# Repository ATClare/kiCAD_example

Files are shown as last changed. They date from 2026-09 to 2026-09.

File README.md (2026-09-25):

# ESP32 soil moisture and servo valve — Rev A

An engineer-reviewable, low-voltage irrigation prototype: a capacitive soil probe, ESP32 controller, servo-operated valve interface, three panel LEDs, printable enclosure, and a local web dashboard with moisture history and threshold notifications.

**Release status:** design prototype. Electronic connectivity, CAD geometry, firmware compilation, and software behavior can be checked without hardware. Valve torque, actual closure, water flow, electrical transients, moisture calibration, and printed-part fit require the acceptance tests below. This package is not a validated unattended watering product.

## Start here

| Deliverable | File |
|---|---|
| Electronic schematic, readable without KiCad | [Schematic PDF](electronics/soil_valve.pdf) |
| Editable schematic and project | [KiCad project](electronics/soil_valve.kicad_pro), [schematic](electronics/soil_valve.kicad_sch) |
| Component list and exact connectivity | [BOM](electronics/bom.csv), [net map](electronics/connectivity.json), [KiCad-exported netlist](electronics/soil_valve.net.xml) |
| Editable parametric CAD | [CadQuery model](mechanical/enclosure.py) |
| Assembled enclosure CAD | [STEP assembly](mechanical/exports/enclosure_assembly.step) |
| Individual STEP and print-ready STL files | [CAD exports](mechanical/exports/) |
| ESP32 application and control logic | [main.cpp](firmware/src/main.cpp), [control.h](firmware/include/control.h) |
| Dashboard | [Interactive offline demo](docs/dashboard-demo.html), [HTML source](firmware/web/index.html), [demo screenshot](docs/dashboard-demo.png) |
| Engineering rationale, wiring and procurement | [Electrical design](docs/electrical-design.md) |
| Mechanical dimensions and assembly | [Mechanical design](docs/mechanical-design.md) |
| Failure analysis and bench sign-off | [Audit and acceptance plan](docs/audit-and-acceptance.md) |
| Automated verification evidence | [Verification report](docs/verification.md) |
| Manufacturer references | [Sources](docs/sources.md) |

To preview the dashboard without a device, open `docs/dashboard-demo.html` in a browser. Alternatively, open `firmware/web/index.html` and append `?demo=1` to its address. The demo explicitly labels its simulated data and disables hardware controls. The dashboard needs no CDN, JavaScript framework, cloud service, or internet connection.

## Design assumptions

- One indoor/sheltered plant zone, externally supplied regulated **5.0 V / 3 A** power.
- Genuine **Espressif ESP32-DevKitC V4 with ESP32-WROOM-32E**, using the documented 38-pin headers. Other ESP32 boards need pin and power-path review.
- **DFRobot SEN0193** capacitive probe supplied at 3.3 V; only its sensing section enters soil. Do not immerse its electronics.
- **Hitec HS-311** positional servo, externally mounted above the water path. A small low-pressure valve must have measured torque and compatible linkage travel. The servo bracket and slotted linkage plate are supplied, but the valve-specific attachment dimensions are not known.
- A gravity reservoir is the intended first test source; use a spill tray and limit available water. No pressure-bearing printed plumbing parts are supplied.
- Measurement is **relative moisture percent**, not volumetric water content (VWC). Actual VWC requires soil-specific reference measurements and a different calibration model.

No valve, supply, or existing parts were specified. These assumptions make the design concrete; substitutions and the actual valve are audit inputs rather than proven equivalents.

## Operation

At power-on the firmware commands the servo to its configured closed position, leaves automatic watering disarmed, starts measurements, and creates a password-protected Wi-Fi access point. Calibration survives restart; arming, faults, watering reservations, graph history, and events do not. The boot event makes this reset visible.

The probe is sampled at 4 Hz, averaging 16 calibrated ADC millivolt readings per sample and applying an exponential filter with coefficient 0.25. Five consecutive plausible samples establish readiness. The initial example calibration is **not authorized for watering** until you save measured endpoints.

After arming, moisture below the low threshold sets watering demand. Demand remains set through the middle band and clears at the high threshold. Defaults are 30% and 55%; these are example settings, not crop recommendations. Each opening command lasts nominally 5 seconds, followed by at least 60 seconds closed for soaking. The 20 ms control task imposes small scheduling tolerance; verify actual pulse duration on hardware.

Each pulse reserves its full five seconds in a 30-second budget, even when stopped early. Reservations clear only after one complete hour with **no new pulse starts**, a conservative rule that avoids bursts at fixed clock boundaries. A seventh requested pulse latches a budget fault. After the quiet hour, reset the fault and explicitly re-arm. Manual pulses share the same calibration, fault, soak, and budget restrictions and require automatic mode to be disarmed.

Opening the normally closed STOP loop commands closure, disarms, and latches a fault. Three implausible sensor samples latch a sensor fault; even the first implausible sample inhibits or terminates watering. Stale samples also latch a fault. Fault reset does not re-arm. Loss of a browser connection does not stop armed automation; the physical STOP remains the local control.

**A servo command does not establish actual valve position.** There is no flow sensor or valve feedback. A stalled servo, broken linkage, controller failure, or loss of power can leave the valve open. STOP is a firmware interlock, not a hardwired safety function. Where flooding matters, the engineering release must add independently verified fail-closed actuation or a separate normally closed shutoff.

## Wiring summary

Use the schematic and [electrical design notes](docs/electrical-design.md) as the wiring authority. Local net labels of the same name are electrically connected. `U1.J2` and `U1.J3` refer to the development board's own headers; standalone `J2` and `J3` are project probe and servo connectors.

| Function | ESP32 GPIO | DevKit header |
|---|---:|---|
| Probe divider output | 34, ADC1 | J2 pin 5 |
| Servo PWM, through 5 V buffer | 18 | J3 pin 9 |
| Green LED | 25 | J2 pin 9 |
| Amber LED | 26 | J2 pin 10 |
| Red LED | 32 | J2 pin 7 |
| Normally closed STOP loop input | 27 | J2 pin 11 |
| 3.3 V probe supply | — | J2 pin 1 |
| 5 V board power through RUN link | — | J2 pin 19 |
| Common ground | — | J2 pin 14; J3 pins 1, 7 |

Green flashes while disarmed and is steady while armed. Amber means **OPEN commanded**. Red indicates a latched fault, missing calibration, or configuration-save failure. Green is a firmware heartbeat/mode indicator, not proof of network access or sensor accuracy.

Connect the servo supply and return directly to the fused supply distribution point. Do not feed servo current through the ESP32 board, its regulator, USB cable, or a solderless breadboard. Inspect connector polarity before energizing; the input is fused but has no reverse-polarity protection.

## Build and flash

The build is pinned to PlatformIO `espressif32@6.9.0`, which selects Arduino-ESP32 2.0.17. The firmware uses that version's LEDC API; upgrading to Arduino 3.x requires migration and retesting. Python 3.12 was used for tooling.

```powershell
python -m pip install platformio==6.2.0
Copy-Item firmware/include/secrets.example.h firmware/include/secrets.h
# Edit secrets.h: two different, unique passwords of at least 12 characters.
python -m platformio run -d firmware
```

This workspace contains a generated, ignored `firmware/include/secrets.h` with random credentials for the verified local build. Read that file locally to obtain them, or replace them and rebuild. The template must remain free of actual credentials. The firmware refuses to start networking with short or placeholder passwords.

On Windows, if the compiler reports a process-launch error from a long project path, run `powershell -ExecutionPolicy Bypass -File tools/build_firmware.ps1`. This temporarily maps the workspace to a short drive path and removes that mapping on completion. Add `-Upload -Port COM5` to build and flash through the same workaround. The portable ZIP excludes the local credentials, so create `secrets.h` from the template after extracting it elsewhere.

Before connecting the board's USB port: turn **SW1 OFF**, remove **JP1**, and disconnect the servo during initial commissioning. Espressif specifies mutually exclusive supply methods; never power the DevKit from its 5 V header and USB simultaneously. The lid is removed for USB access.

```powershell
python -m platformio run -d firmware -t upload --upload-port COM5
python -m platformio device monitor -d firmware --port COM5
```

Replace `COM5` with the actual port. Close the serial monitor before another upload. The dashboard is embedded in flash by `embed_ui.py`; a separate filesystem upload is unnecessary. After programming, disconnect USB before replacing JP1 and switching on external power.

Join `SoilValve-<device identifier>`, use `AP_PASSWORD`, then open `http://192.168.4.1`. Authenticate as `admin` with `ADMIN_PASSWORD`. A phone may need to remain connected to a network with no internet access. There is no captive portal.

## Commissioning and calibration

1. Keep water disconnected and the servo horn detached. Verify power polarity, fuse, common ground, and the ADC divider with a meter. Check the STOP input changes state when its loop opens.
2. Power the system; confirm disarmed status, red calibration indication, and a closed-position PWM signal. Verify the servo supply stays at or above 4.8 V while the servo moves.
3. Adjust `CLOSED_US` and `OPEN_US` in `main.cpp` for the actual mechanism. Defaults are 1050 and 1950 microseconds at 50 Hz, within the HS-311's documented nominal 900–2100 microsecond range. Rebuild if changed. Never force the servo against a hard stop.
4. Measure ADC millivolts in representative dry soil at the intended insertion depth and packing. Allow readings to stabilize. Repeat in representative wet soil. Record soil type, temperature, preparation, supply voltage, depth, and each endpoint's variation.
5. Save both endpoints and thresholds. Required range: `100 <= wet < dry <= 2150 mV`, dry–wet separation at least 200 mV, thresholds between 5 and 95%, with at least five percentage points of separation. Reverse response or insufficient span needs investigation, not inverted wiring guesses.
6. Confirm the same samples map to approximately 0 and 100%, and use intermediate gravimetric samples if assessing accuracy. Display clamping to 0–100% does not imply physical accuracy. Tune thresholds for the actual soil and plant under observation.
7. Attach the horn and linkage only after verifying the close direction. Test travel without water, including STOP, reset, and power interruption. Measure valve torque throughout travel.
8. Use a small reservoir and catch vessel. After the initial 60-second inhibit, issue a manual pulse; measure volume, closing leakage, and time to wet the probe. Complete [the acceptance plan](docs/audit-and-acceptance.md) before arming automatic mode.

The readout uses `100 × (dry_mV − measured_mV) / (dry_mV − wet_mV)`, clamped to 0–100. Calibration is specific to this probe, divider, board, soil, and installation. Values from a tutorial or a different probe must not be reused as measured endpoints.

## Dashboard and data contract

The chart retains 1,440 one-minute samples in ESP32 RAM (up to 24 hours). Timestamps are elapsed seconds since boot, not wall-clock time; there is no RTC or NTP. Invalid samples are JSON `null` and produce gaps. CSV export downloads the current history, including ADC millivolts and valve command state. Short pulses can fall between history samples, so the event log is the appropriate record of valve command transitions.

The latest 32 events contain low/high threshold crossings, commands, faults, and mode changes. These in-page notifications are retained on the controller even if the browser is closed, until overwritten or rebooted. They are not email, phone push notifications, or a durable audit log. Recalibration clears graph history and leaves the controller disarmed.

| Endpoint | Method | Purpose |
|---|---|---|
| `/` | GET | Embedded dashboard |
| `/api/status` | GET | Current status, calibration, events, boot ID, control token |
| `/api/history` | GET | Chronological sample array |
| `/api/config` | POST | URL-encoded `dryMv`, `wetMv`, `low`, `high`; saves validated calibration |
| `/api/command` | POST | URL-encoded `action=arm`, `pulse`, `close`, or `reset` |

All useful routes require HTTP Basic authentication. Mutations also require the per-boot `X-Control-Token` obtained from authenticated status. The access point is password protected, but HTTP is not TLS. Use only a trusted local connection; this design has no internet exposure, remote update service, or remote credential provisioning. Protect the device and source secrets physically. A reboot produces a new boot identifier and token.

## Reproduce the design checks

```powershell
python -m pip install -r tools/requirements.txt
python tools/generate_schematic.py
kicad-cli sch erc -o electronics/erc.rpt electronics/soil_valve.kicad_sch
kicad-cli sch export pdf -o electronics/soil_valve.pdf electronics/soil_valve.kicad_sch
kicad-cli sch export netlist --format kicadxml -o electronics/soil_valve.net.xml electronics/soil_valve.kicad_sch
python tests/check_netlist.py
python mechanical/enclosure.py
g++ -std=c++17 tests/control_test.cpp -o tests/control_test.exe
./tests/control_test.exe
python tests/browser_test.py
python -m platformio run -d firmware
```

`kicad-cli` must be on PATH, or use its installed absolute path. Browser tests currently point to the Windows Chrome installation; change `executable_path` in the test for another installation. Any C++17 compiler can run the host control tests; the local verification used Zig's C++ frontend. The CAD source is authoritative for geometry; generated files may be overwritten. Schematic regeneration assigns new UUIDs, so review regenerated schematic diffs with the netlist.

## Engineering handoff

The schematic specifies a wired module/perfboard assembly, including all external passives and panel wiring. The purchased DevKit, sensor, and servo contain their own manufacturer circuitry. A routed carrier PCB, Gerbers, production harness drawing, waterproof certification, and a valve-specific adapter are not part of Rev A. The carrier CAD is a mechanical drill template, not a PCB layout.

An engineer should review the source references, electrical calculations, pin mapping, firmware state machine, mechanical stack-up, and failure table; then record the actual parts and execute the hardware acceptance plan. Do not interpret a clean ERC, successful compilation, or valid CAD solid as proof of physical operation.

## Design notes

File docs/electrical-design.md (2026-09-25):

# Electrical design and build notes

## Architecture and interfaces

The native KiCad schematic is one A3 sheet divided into power, probe interface, servo interface, full DevKit header mapping, panel LEDs, and STOP input. The project includes its own symbol library and library tables; open the `.kicad_pro` for correct library resolution. The custom module symbol numbers its pins `J2.1` through `J3.19` to preserve Espressif's physical header identities. Unused module header pins have explicit no-connect markers. No GPIO boot-strapping pins are used by the application.

The schematic describes a complete external circuit around purchased modules. Espressif's original DevKit schematic remains the authority for its regulator, USB bridge, boot circuit, and RF module. The project does not reproduce proprietary probe or servo internals.

## Supply path

J1 pin 1 → F1 2 A fuse → SW1 → `+5V`. This rail powers J3 servo pin 2 and U2 pin 5. JP1 connects this rail to `MCU_5V` and U1.J2.19. J1 pin 2 is the star ground. Connect U1's exposed ground header pins to that ground; keep the servo's return conductor separate until the star point.

Specify an enclosed regulated 5.0 V, 3 A supply with a low-voltage isolated output. Operate electronics in a sheltered dry location. There is no battery charger, mains circuitry, surge-rated outdoor interface, or reverse-polarity protection. Use a keyed supply connector and verify polarity. F1 protects wiring against sustained excessive current; it does not detect a stalled servo at its normal stall current.

Allow approximately 0.8 A servo stall current, 0.5 A as a conservative ESP32 board transient allocation, and 0.05 A auxiliary allocation: 1.35 A design load. This is a budget, not measured consumption. The 3 A supply provides margin but does not remove the need to measure droop and inrush. Target 4.8–5.2 V at the servo and U2 during operation; AHCT buffer recommended supply range is 4.5–5.5 V, while the servo minimum is 4.8 V.

Use short 22 AWG or larger power distribution conductors, appropriately rated connectors, and insulated solder joints. C1 is a polarized 1000 µF, ≥10 V electrolytic close to J3, positive at pin 1. At 0.8 A for 1 ms, an ideal 1000 µF capacitor alone would droop 0.8 V (`I × dt / C`), so it cannot substitute for an adequate supply. C2 provides local MCU input bulk; C5 is within 5 mm of U2 supply pins. Test fuse survival on repeated cold starts and check capacitor polarity before power-up.

## Sensor conditioning

J2 project harness: pin 1 = 3V3, pin 2 = GND, pin 3 = PROBE_OUT. Build an adapter to the purchased sensor's connector; do not assume that project pin numbering equals DFRobot's plug order or clone cable colors.

R1 = 10 kΩ and R2 = 20 kΩ, both 1%, divide the probe output to GPIO34/ADC1. Nominal division is 2/3. A 3.0 V sensor output becomes 2.0 V; a supply-limited 3.3 V becomes 2.2 V. With 1% worst-case divider tolerance, the ratio is approximately 0.662–0.671. ADC1 avoids the original ESP32 ADC2/Wi-Fi resource conflict. Firmware uses `analogReadMilliVolts()` and 11 dB attenuation.

The divider presents a 30 kΩ load to the probe. Validate output behavior under that load; no output-drive accuracy is assumed. The Thevenin resistance is 6.67 kΩ and C3 = 100 nF gives a nominal 0.667 ms time constant (~239 Hz cutoff). Software filtering handles slower noise. Route PROBE_OUT and GND together, separate them from servo leads, and keep the analog node physically short. This is a short-cable indoor interface, without certified ESD/lightning protection.

The divider pulls ADC voltage to ground after sensor disconnection. Firmware treats values below 100 mV or above 2150 mV as implausible. Values inside that window can still be wrong: a stuck sensor, ground offset, or partially shorted cable cannot always be detected from one analog channel. Calibration and the bounded watering policy reduce consequences but do not provide fault coverage for all sensor failures.

Never connect 5 V directly to the ADC. The divider is dimensioned for the specified 3.3 V-powered probe; it is not a general-purpose protected industrial analog input.

## Servo signal

GPIO18 → U2 pin 2 (A), with R3 = 100 kΩ to GND. U2 pin 1 (/OE) and pin 3 go to ground; pin 5 goes to +5V. U2 pin 4 (Y) → R4 = 220 Ω → J3 pin 3. The AHCT input recognizes 3.3 V logic while providing a 5 V servo signal. Use **SN74AHCT1G125DBVR**, not HC logic with a higher input threshold. Verify the SOT-23-5 breakout's numbering against the TI package drawing.

J3 is 1 GND, 2 +5V, 3 signal. Match the actual servo lead polarity before connecting. Firmware produces 50 Hz pulses, nominally 1050 µs closed and 1950 µs open. These are commissioning settings, not established valve angles. The external 100 kΩ pulldown suppresses floating input during reset but does not generate a closed-position servo pulse before firmware starts. Servo movement may occur during power sequencing; characterize it with the horn unloaded.

## LEDs and STOP

GPIO25/26/32 each drive a 680 Ω resistor followed by an LED anode; all cathodes return to ground. For a 2.0 V LED forward drop, nominal current is `(3.3 − 2.0) / 680 = 1.9 mA`. Select high-efficiency diffused LEDs visible at this current. White/blue substitutions may be dim due to higher forward voltage. The schematic labels LED pins A=2, K=1; match polarity by datasheet and flat/short lead, not a harness assumption.

J4 connects an external maintained normally closed STOP contact between STOP_SW and GND. R8 = 1 kΩ connects the loop to GPIO27; R9 = 10 kΩ pulls GPIO27 to 3.3 V; C6 = 100 nF filters interference. The firmware additionally enables its internal pullup. A healthy closed loop produces a logic low; opening the loop or disconnecting its cable produces a high. A short across the loop cannot be detected. Contact bounce may latch a conservative fault; release STOP and explicitly reset it.

This input is polled by the controller and has no independent hardware authority over power or valve closure. Mark it as STOP/interlock rather than claiming a safety-rated emergency-stop function.

## Procurement supplement

The electrical CSV contains references, values, descriptions, and the buffer footprint. Most components are intentionally through-hole or wired modules, with no PCB footprint assignment. This table supplies parts not fully described by a reference value.

| Item | Quantity | Procurement specification / acceptance |
|---|---:|---|
| U1 | 1 | Espressif ESP32-DevKitC V4, ESP32-WROOM-32E, 38-pin board |
| Probe | 1 | DFRobot SEN0193 with mating cable; verify supply and output |
| Servo | 1 | Hitec HS-311 with original 24T horn and mounting screws |
| U2 and adapter | 1 each | TI SN74AHCT1G125DBVR, SOT-23-5 breakout with short decoupling path |
| PSU | 1 | Regulated 5.0 V/3 A isolated enclosed supply, keyed low-voltage connector |
| F1 and holder | 1 each | 2 A fast fuse rated ≥32 VDC; validate inrush and wire coordination |
| SW1 | 1 | SPST maintained toggle, ≥3 A at ≥12 VDC; 12 mm panel bushing |
| STOP contact | 1 | Maintained/latching NC pushbutton, 22 mm panel hole; body depth ≤30 mm |
| JP1 | 1 | Two-pin removable shunt/header rated ≥1 A; label RUN/USB |
| J1–J4 harnesses | 4 | Keyed insulated connectors; J1/J3 rated ≥3 A; clearly label polarity |
| D1/D2/D3 | 1 each | Green/amber/red, 5 mm diffused high-efficiency LED, 6.5 mm-hole holders |
| Resistors | 9 | R1/R2 1%; all ≥0.125 W; values from schematic |
| Capacitors | 6 | C1 electrolytic 1000 µF/10 V; C2 10 µF/10 V ceramic; others 100 nF/≥10 V X7R |
| Carrier | 1 | 100 × 60 mm insulated/perfboard carrier with holes at ±45, ±25 mm |
| Cable glands | 3 | M12 gland bodies, hole requirement 12.2 mm, cable range suited to each lead |
| Enclosure screws | 4 | M3 × 16 pan head, head diameter ≤6.4 mm; tap or qualify printed pilot holes |
| Carrier screws | 4 | M3 × 8, insulating washers as needed |
| Valve and hoses | 1 set | Low-pressure, approximately quarter-turn valve; measured travel/torque required |
| Servo bracket hardware | 1 set | M3 servo fasteners and M4 base fasteners, washers, nuts, spacers as measured |

Part choices with dimensional envelopes are procurement requirements, not universal compatibility claims. Record exact manufacturers and lot numbers in the acceptance sheet before building.

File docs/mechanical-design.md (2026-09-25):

# Mechanical design and assembly

## Model authority and coordinate system

`mechanical/enclosure.py` is the editable CadQuery source, with dimensions in millimetres. STEP files contain exact boundary-representation solids; STL files are tessellated printing derivatives. A positive solid-volume and validity report is exported with each generation. The assembled STEP contains the base, lid, and a carrier reference plate. The external servo bracket and linkage plate are separate parts.

For the enclosure, X is the long direction, Y the short direction, and Z points out of the base. The enclosure is centred at X=Y=0; its external floor is Z=0. The front cable-entry wall is Y=−50. Installed lid surfaces are Z=55 to 58; its locating rails extend down to Z=52.

## Critical dimensions

| Feature | Geometry / coordinates |
|---|---|
| Base external size | 140 × 100 × 55 |
| Walls / floor | 3 / 3 |
| Base internal nominal space | 134 × 94 × 52, before posts and rails |
| External vertical corner radius | 4 |
| Lid plate | 140 × 100 × 3 |
| Lid locating rails | 2 thick, 3 deep; interrupted around screw posts |
| Rail-to-wall nominal clearance | 0.3 per side |
| Lid fastener centres | (±61, ±41) |
| Base corner posts | Ø10; Ø2.5 pilot, depth 16 from top |
| Lid through / counterbore | Ø3.4 through; Ø6.4 × 1.5 deep |
| Carrier board outline | 100 × 60 × 1.6 |
| Carrier mounting centres | (±45, ±25) |
| Carrier support top | Z=11; pilot Ø2.5 |
| Cable gland holes | Ø12.2; X=−38, 0, 38; Y=−50; Z=24 |
| LED holder holes | Ø6.5; X=−18, 0, 18; Y=20 |
| STOP panel hole | Ø22.2; X=35; Y=−15 |
| Power switch hole | Ø12.2; X=−35; Y=−15 |

The CAD carrier is a drilling and fit reference. Fabricate the real carrier from suitable electrically insulating material or use perfboard trimmed and drilled to these dimensions. Do not interpret the STL carrier as a designed electrical PCB. Secure the DevKit in sockets on the carrier and mount the discrete interface components nearby. Keep the RF antenna end free of copper and metal per the module guidance. Reserve space above the carrier for wiring and panel control bodies.

The CAD validates base/lid interference only; exact purchased board, terminal, gland-nut, switch, and cable envelopes are not modelled. Select a STOP assembly with total intrusion below the lid of at most 30 mm. Even then, check it against component height on the carrier. Keep tall electronics away from the two control centres and route wiring clear of screw posts. The right and left gland centres are offset from carrier mounting posts, but gland locknuts and lead bend radii still require inspection.

## Printing

Initial settings: PETG, 0.2 mm layers, four perimeters, at least five top/bottom layers, and 30–40% infill. These are starting fabrication parameters requiring qualification on the actual printer. Avoid assuming a PLA part will maintain stiffness in sun or a warm enclosure.

STLs are translated onto Z=0. The base prints open side upward. The lid STL is inverted, placing its outer face on the bed and its locating rails upward; preserve the visible labels when choosing a build surface. The servo bracket is translated onto its feet and needs support beneath its elevated cross plate. Print a hole/clearance coupon before committing to all parts. Ream or drill holes to nominal size as needed, and tap M3 pilots carefully; repeated service may justify redesigning for threaded inserts.

The source does not include a gasket groove. The lid, LED holes, control bushings, and printed layer structure are not sealed or IP-rated. A gasket, selected sealed panel components, and validated glands would require a revised stack-up and ingress testing. Keep Rev A sheltered and dry, with cable drip loops.

## Enclosure assembly

1. Deburr the parts and confirm the lid rails seat without force. Do not use the screws to pull a warped lid flat.
2. Fit the three M12 glands from the front. Place their locknuts inside and ensure they do not touch the carrier or crush wires.
3. Install the power toggle and latching NC STOP control. Fit green, amber, and red LEDs under READY, WATER, and FAULT, using the specified panel holders.
4. Mount the 100 × 60 carrier on the four internal posts with M3 × 8 screws. The board bottom is at Z=11. Prevent solder-side protrusions from contacting conductive hardware.
5. Install the ESP32 and interface circuitry. Retain slack for lid removal, strain-relieve panel harnesses, and mark the RUN jumper. Verify the lid closes without pushing any component or lead.
6. Fit the lid with M3 × 16 screws. The counterbore is sized for a pan head no larger than Ø6.4; different heads require a model change. Limit torque according to the printed-thread qualification, not a generic steel-thread torque.

USB access is through the removed lid. This deliberately keeps the outside face simple and permits direct verification that SW1 is off and JP1 removed before connecting a computer.

## Servo bracket and linkage

The external bracket has a 76 × 44 × 4 top plate, a 40.8 × 20.8 servo-body aperture, and adjustable 7 × 3.4 flange slots centred at X=±24.5, Y=±5. The bracket feet enlarge the overall envelope to 96 × 44 × 44. Four 9 × 4.5 mounting slots at X=±43, Y=±13 attach it to a rigid base. The HS-311 published body envelope is 40 × 20 × 36.5; mounting flange and cable clearances must be checked on the purchased part before printing. The slot range is an allowance, not a verified fit report.

Use the manufacturer's 24-tooth horn. The generic 55 × 12 × 4 linkage plate contains an Ø3.2 hole at X=−18 and a 25 × 3.4 slot centred at X=8. Drill/fasten an appropriate horn attachment on the actual mechanism; do not depend on one screw's friction alone to transfer valve torque. The model intentionally does not invent a printed servo spline or a valve-shaft interface.

Mount the valve and servo on a common rigid plate so that reaction loads are not carried by soft tubing. Arrange linkage axes to avoid over-centre binding. A nominal 90-degree servo motion is only a starting point; adjust pulse endpoints and linkage geometry to reach both valve positions without servo stall. Keep servo electronics and connectors dry; the servo is not treated as a waterproof actuator.

Published servo stall torque at 4.8 V is approximately 3 kgf·cm = 0.294 N·m, but stall torque is not a continuous operating rating. As a conservative initial selection criterion, choose a valve whose measured worst-case breakaway/running torque is no more than **0.05 N·m** at the servo shaft after linkage ratios and losses. This also lies below the published peak-efficiency torque (~0.059 N·m at 4.8 V). Verify under the intended pressure, temperature, deposits, and hose loading. A larger valve may require a different servo, bracket, power supply, and fuse.

The current design does not guarantee closure without electrical power. An added spring alone may not back-drive a geared hobby servo; a fail-closed redesign must prove the entire power-loss behavior, not simply add a spring to the drawing.

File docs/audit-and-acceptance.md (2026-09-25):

# Audit, failure analysis, and acceptance plan

## Requirements traceability

| Requested capability | Implementation | Audit evidence / limitation |
|---|---|---|
| ESP32 soil moisture sensor | SEN0193 → divider/filter → GPIO34 | Schematic and ADC code; soil-specific bench calibration required |
| Full electronics schematic | Native KiCad module-level circuit and PDF | ERC and exported connectivity test; purchased modules retain manufacturer internals |
| Casing CAD | Parametric enclosure, lid, STEP assembly, STLs | Solid validity and base/lid collision check; print and actual component fits pending |
| Servo opens valve | 50 Hz PWM, AHCT buffer, external servo bracket | Firmware compile and state-machine tests; actual valve selection and linkage commissioning pending |
| Panel status LEDs | Green/amber/red outputs with current limiting | Schematic, firmware mapping, lid openings |
| Moisture history graph | Embedded canvas UI, 1,440 samples, CSV | Desktop/mobile browser checks with mocked data; device heap/load testing pending |
| Threshold notifications on same UI | Low/high crossings, fault/event list, status banner | Browser checks; no external notification service |
| Professional audit documentation | README, source links, calculations, test plan | Rev A handoff, not engineering certification |

## Failure review

| Failure / trigger | Detection and designed response | Residual risk / required action |
|---|---|---|
| Probe disconnected or output near ground | ADC divider pulls low; first bad sample inhibits opening and commands closure; three bad samples latch fault | Verify discharge/read latency; a plausible stuck value is not detected |
| Probe ADC too high | Above 2150 mV is rejected | Wrong wiring may damage GPIO before software acts; inspect wiring before power |
| Sensor drifts/sticks dry | No comprehensive detection; 5-second pulses, soak, conservative budget | Limited water can still be unwanted; use independent flow/volume controls for consequential installations |
| STOP cable open | Pullup reads high; close command, disarm, latched fault | GPIO/firmware failure or shorted loop can defeat it; no safety claim |
| Browser closes / Wi-Fi fails | Local automation continues; browser indicates stale connection when detectable | Operator must use physical STOP; notifications are unavailable while disconnected |
| Slow/malicious HTTP client | Control task runs separately; network writes are outside the mutex | FreeRTOS scheduling, heap exhaustion, and watchdog behavior require device stress tests |
| Servo jam or linkage detached | No direct feedback; command still reports CLOSED/OPEN | Valve may remain open indefinitely; add position/flow sensing or independent shutoff |
| Servo shorts | Input fuse and supply limiting may operate | Verify fuse/wire coordination; a normal-current stalled servo does not blow F1 |
| Power loss / brownout | PWM may stop; restart commands close and disarms | A mechanical valve may remain open during outage; software cannot guarantee closure |
| Controller task hangs | Approximately 3-second task watchdog requests reset | This is secondary recovery, not an independent hard deadline or fail-close mechanism |
| Configuration out of bounds | Rejected, no save or activation | Incorrect but in-range calibration is operator error; record actual endpoints |
| NVS write failure | Return error, flag storage failure, reject new watering commands | Commission storage; power-loss behavior during save must be tested |
| Restart bypasses RAM budget | Always disarmed after restart | A deliberate operator can re-arm and reset reservations; this is not a persistent water meter |
| Water/condensation reaches electronics | No moisture-in-enclosure detection | Rev A is unsealed; dry sheltered use, or redesign and test sealing |
| Incorrect polarity / simultaneous USB power | No reverse-polarity circuit; documented isolation procedure | Hardware damage possible; verify polarity and supply exclusivity |

## Hardware acceptance procedure

All items below are **pending physical tests**. Record measured values, test equipment, calibration dates, photographs, firmware hash, component versions, and pass/fail. Stop and revise the design if any criterion fails.

1. **Unpowered inspection:** verify all 19 named nets against the wiring; check polarity, resistor values, connector identities, insulation, and no power-to-ground short. Confirm the STOP uses a normally closed maintained contact.
2. **Power integrity:** start with a current-limited supply and no servo. Verify 3.3 V rail within the board's requirements. Add servo unloaded, then representative mechanical load. Scope +5V at J3 and +3V3 at U1 during repeated motion and Wi-Fi traffic. Accept only if servo supply remains ≥4.8 V, U2 remains within 4.5–5.5 V, and ESP32 stays stable. Measure inrush and fuse/connector temperatures.
3. **PWM:** scope GPIO18 and J3 signal. Verify 50 Hz, configured pulse endpoints, logic levels, and polarity. With a known valid calibration and dry stimulus, measure a normal pulse at approximately 5.00 s; initial acceptance ceiling 5.10 s under sustained UI traffic. A tighter application limit needs a tighter measured timing budget or hardware cutoff.
4. **Startup / reset:** power-cycle with wet and dry stimuli, and restart during an open pulse. Verify no automatic watering resumes without explicit arming. Characterize any uncontrolled motion before the first valid PWM. Repeat USB/external power transitions using the prescribed sequence.
5. **Interlock:** while opening, disconnect J4 or operate STOP. Closure command must change within 100 ms in normal operation. Verify the fault remains latched after restoring the loop and that reset leaves the controller disarmed. Observe physical closure time separately; command latency is not valve latency.
6. **Probe faults:** disconnect each probe lead and short output to ground using a controlled fixture. Verify watering is inhibited, a running command closes promptly, and persistent implausible values latch a fault. Never inject a voltage exceeding the ADC pin rating. Record which cable faults remain plausible and undetected.
7. **Threshold and soak:** apply controlled analog voltages through an appropriate test fixture or calibrated soil samples. Verify below-low starts demand, intermediate values maintain demand after a low crossing, and above-high clears demand. Verify no new pulse begins before 60 seconds after closure, including manual requests and early STOP closure.
8. **Budget:** request six full pulses separated by soak time; verify the seventh request faults. Verify no reset bypass before one hour since the last accepted pulse start. Verify reset plus re-arm after that interval. Reboot behavior must match documented RAM reset and disarming.
9. **Persistence:** save measured calibration, reboot, compare exact fields, and verify disarmed mode. Interrupt power during an NVS save under controlled dry conditions; accept only a valid old or new configuration, or an uncalibrated inhibited startup. Test a full/failed storage scenario where possible.
10. **Web stress:** authenticated polling, CSV download, multiple tabs, slow clients, malformed values (`NaN`, missing fields, infinities, oversized numbers), missing/wrong token, and unauthenticated requests. Confirm rejected commands have no watering effect. Track free heap through a 24-hour run and verify normal pulse bounds remain satisfied.
11. **History:** log for over 24 hours, verify 1,440-point ring order, invalid-sample gaps, calibration clearing, boot-ID changes, and CSV values. Compare raw ADC against a calibrated meter at five or more voltages and record errors rather than assuming ESP32 ADC accuracy.
12. **Mechanics:** verify gland and panel control fit, carrier-to-lid clearance, antenna clearance, wire strain relief, lid screw retention, and print dimensional tolerances. Cycle the servo mechanism at least 100 times at representative valve load. Inspect loosening, wear, and servo heating. This screening count is not a lifetime qualification.
13. **Hydraulics:** use a small gravity reservoir in a catch tray. Measure opening volume for a five-second command, closure leakage, valve torque, and actual closure time. Repeat at minimum/maximum intended head and supply voltage. Confirm the reservoir's total volume is acceptable if the valve sticks open.
14. **Power-loss consequence:** remove power while the valve is open and observe actual flow. Rev A does not claim automatic closure. An unattended release must either demonstrate independently enforced closure or accept and mitigate the complete reservoir-spill consequence in a signed risk assessment.
15. **Soil validation:** characterize dry/wet endpoints and at least three intermediate reference conditions, repeatability, packing/depth changes, temperature response, and drift. If reporting VWC, establish a traceable gravimetric/volumetric calibration rather than relabeling the relative index.

## Release record

| Field | Engineer entry |
|---|---|
| Reviewer / date / revision | Pending |
| Exact board, sensor, servo, valve and supply | Pending |
| Source/firmware SHA-256 | See generated manifest; record flashed binary separately |
| Valve torque, head/pressure, pulse volume, leakage | Pending |
| Calibration data and uncertainty | Pending |
| Electrical and thermal measurements | Pending |
| Mechanical/ingress qualification | Pending |
| Deviations, mitigations, approvals | Pending |
| Intended environment and permitted operating mode | Pending |

Before manufacturing a PCB or releasing unattended operation, review the missing independent shutoff, feedback, outdoor cable protection, persistent water accounting, enclosure sealing, service access, harness procurement, and regulatory requirements for the actual deployment. These are engineering gates tied to this design's known limitations.

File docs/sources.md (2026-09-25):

# Primary references

Reviewed 2026-09-25. Product specifications below guide the selected design; purchased units and revision-specific drawings must be checked before assembly.

1. [Espressif ESP32-DevKitC V4 user guide](https://documentation.espressif.com/esp-dev-kits/en/latest/esp32/esp32-devkitc/user_guide.html): exact J2/J3 pin numbering, supported module variants, and mutually exclusive USB / 5 V / 3.3 V supply methods. [Manufacturer schematic PDF](https://dl.espressif.com/dl/schematics/esp32_devkitc_v4-sch.pdf).
2. [DFRobot SEN0193 documentation](https://wiki.dfrobot.com/sen0193): capacitive probe connections, nominal supply range 3.3–5.5 V and specified analog output up to 3.0 V. The project uses a 3.3 V supply and a divider; measured calibration is still required. The [product page](https://www.dfrobot.com/product-1385.html) lists typical output information that differs from the wiki's full-range statement; the design conservatively uses the larger range.
3. [TI SN74AHCT1G125 product page](https://www.ti.com/product/SN74AHCT1G125) and [datasheet](https://www.ti.com/lit/ds/symlink/sn74ahct1g125.pdf): 4.5–5.5 V operation, TTL-compatible input, active-low output enable, and five-pin package assignment. These support the 3.3 V to 5 V servo signal translation.
4. [Hitec HS-311 manufacturer page](https://www.hiteccs.com/actuators/product-details/HS-311) and [HS-311 specification sheet](https://www.hiteccs.com/public/uploads/data_sheet/HCS_HS-311_Specsheetv2.2_102-1729889658.pdf): 4.8–6.0 V supply, approximately 40 × 20 × 36.5 mm body, 24T horn, nominal 900–2100 µs control range, current/torque data. Bracket flange fit and mechanical travel require checking on the actual unit.
5. [Espressif Arduino ADC API](https://docs.espressif.com/projects/arduino-esp32/en/latest/api/adc.html): millivolt reading and attenuation concepts. The build's pinned framework source is the version-specific API authority.
6. [Espressif LEDC API](https://docs.espressif.com/projects/arduino-esp32/en/latest/api/ledc.html) and [2.x to 3.0 migration guide](https://docs.espressif.com/projects/arduino-esp32/en/latest/migration_guides/2.x_to_3.0.html): the current documentation describes a different LEDC setup API than the pinned Arduino 2.0.17 implementation. Do not silently upgrade the framework without adapting and validating PWM behavior.

Software package versions, generated-artifact evidence, and limitations are listed in [verification.md](verification.md). No simulated graph is presented as measured plant data.

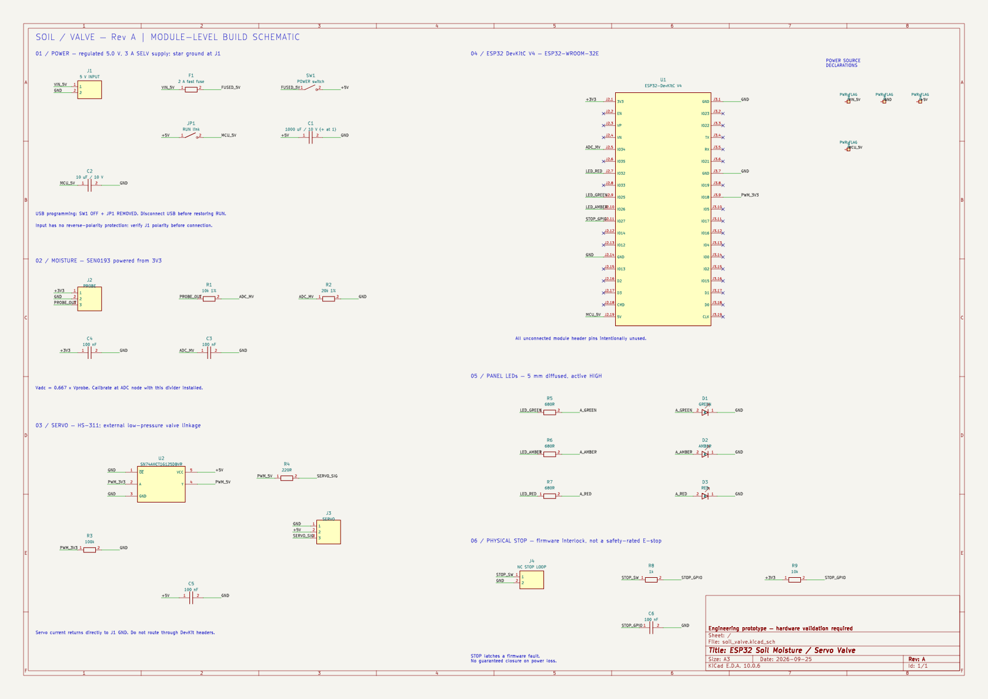
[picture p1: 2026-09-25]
docs/schematic-preview.png

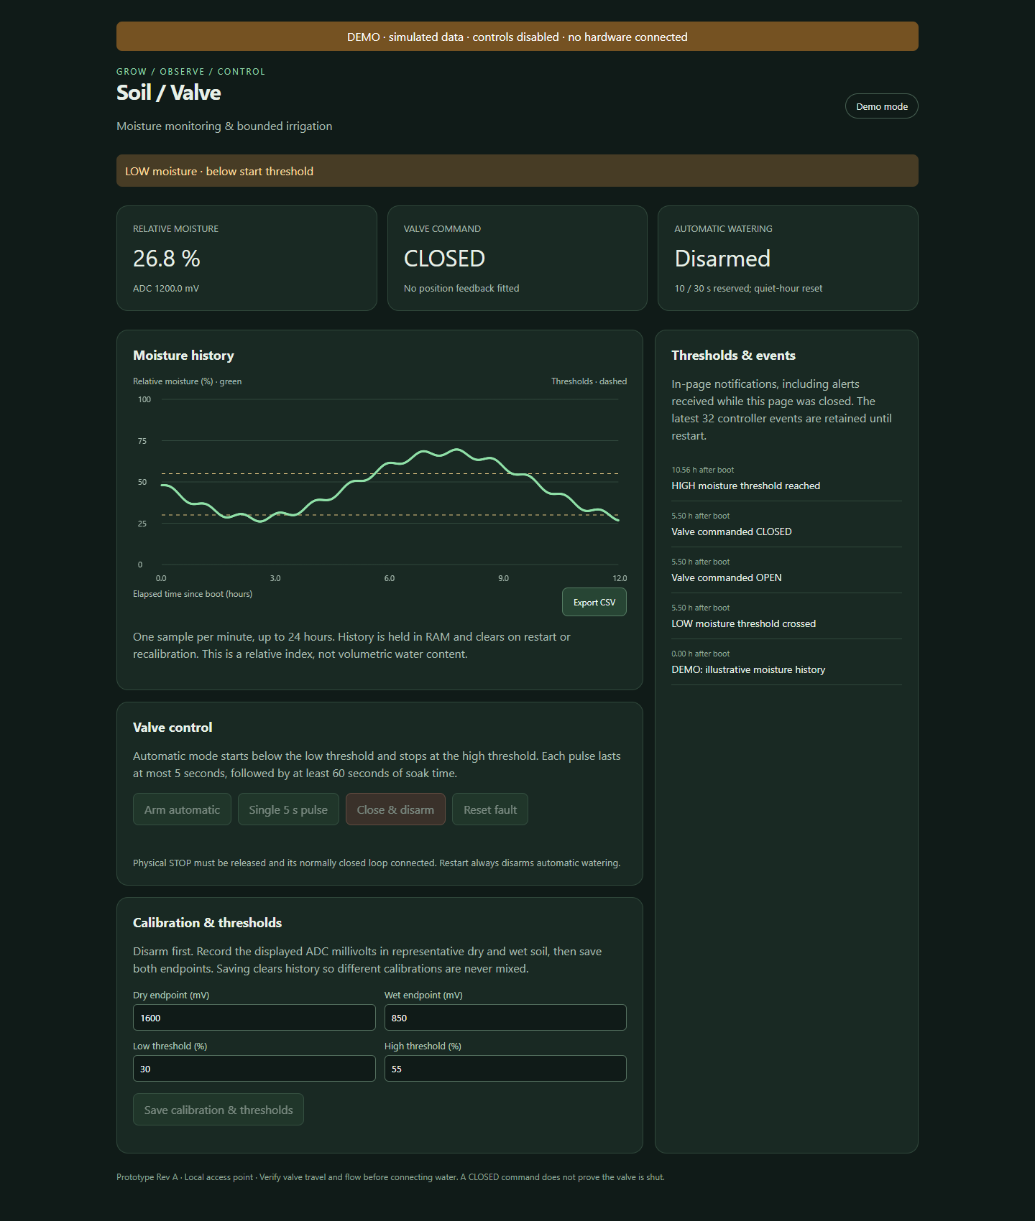
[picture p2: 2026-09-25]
docs/dashboard-demo.png

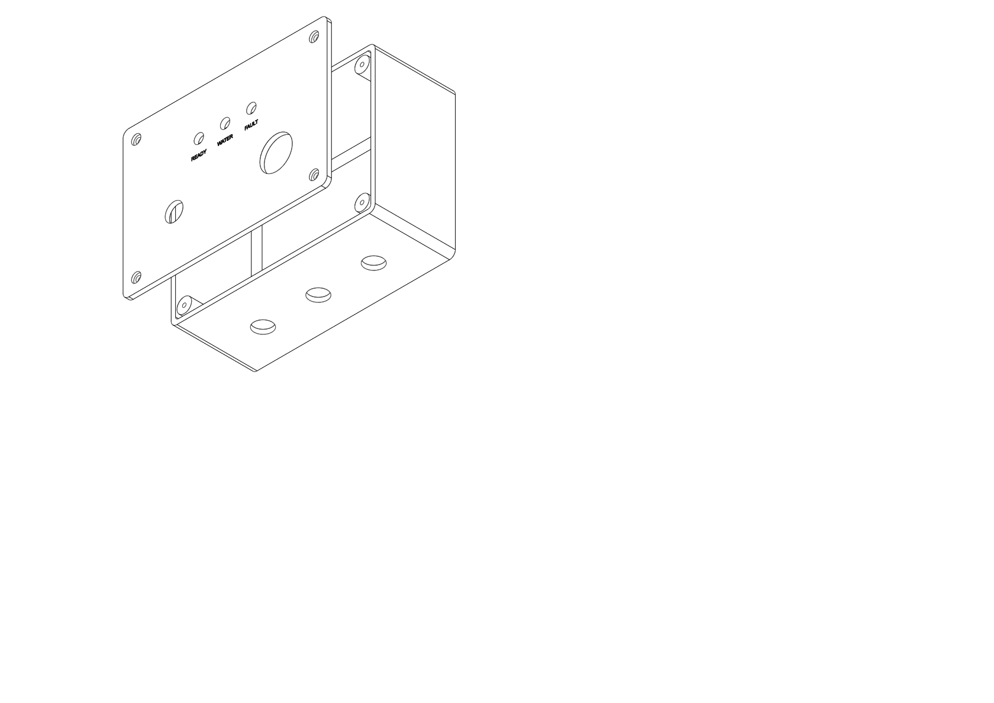
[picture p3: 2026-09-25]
docs/enclosure-preview.png

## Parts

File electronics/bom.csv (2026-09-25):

reference | value | description | footprint
J1 | 5 V INPUT | Keyed 2-pin supply connector, >=3 A; pin 1 positive
F1 | 2 A fast fuse | Replaceable 2 A fuse, rated >=32 VDC
SW1 | POWER switch | SPST maintained switch >=3 A DC
JP1 | RUN link | Remove this jumper AND switch external power OFF before USB connection
C1 | 1000 uF / 10 V (+ at 1) | Low ESR electrolytic, positive terminal pin 1, near servo connector
C2 | 10 uF / 10 V | MCU input bulk capacitor
J2 | PROBE | Board harness: 1=3V3 2=GND 3=analog; verify sensor cable mapping
R1 | 10k 1% | ADC divider top resistor
R2 | 20k 1% | ADC divider bottom resistor, disconnect pulls ADC low
C3 | 100 nF | ADC low pass capacitor at GPIO34
C4 | 100 nF | Probe supply decoupling at connector
U2 | SN74AHCT1G125DBVR | TI SOT-23-5 buffer, TTL input; assemble on SOT23-5 breakout | Package_TO_SOT_SMD:SOT-23-5
R3 | 100k | PWM pulldown keeps buffer input low during reset
R4 | 220R | Series output damping resistor
J3 | SERVO | Servo: 1 black ground, 2 red supply, 3 yellow signal; verify actual unit
C5 | 100 nF | U2 bypass within 5 mm of pins 5/3
U1 | ESP32-DevKitC V4 | Complete purchased Espressif development board; pin numbers refer to its J2/J3 headers
R5 | 680R | LED series resistor, approx 1–2 mA
D1 | GREEN | Off-board 5 mm panel LED, anode=2 cathode=1
R6 | 680R | LED series resistor, approx 1–2 mA
D2 | AMBER | Off-board 5 mm panel LED, anode=2 cathode=1
R7 | 680R | LED series resistor, approx 1–2 mA
D3 | RED | Off-board 5 mm panel LED, anode=2 cathode=1
J4 | NC STOP LOOP | Connect an external normally closed maintained STOP switch between pins 1 and 2
R8 | 1k | Input current limiting; loop open reads high
R9 | 10k | External STOP pullup
C6 | 100 nF | STOP input noise filtering

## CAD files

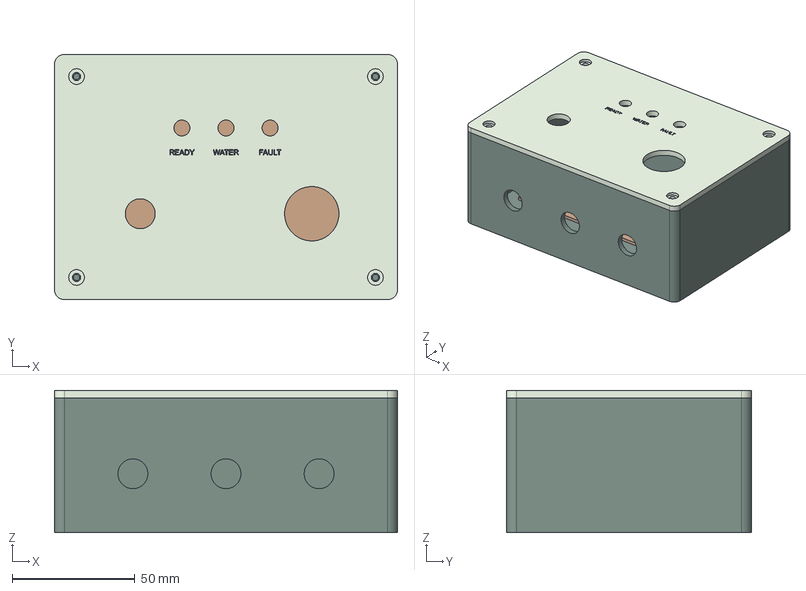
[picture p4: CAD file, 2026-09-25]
mechanical/exports/enclosure_assembly.step
140.0 x 100.0 x 58.0 mm
base
lid
carrier_reference

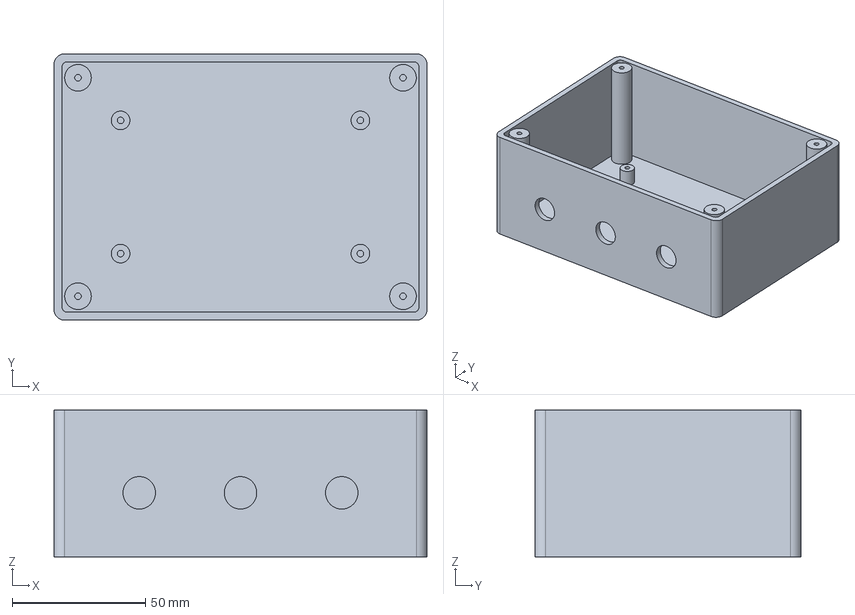
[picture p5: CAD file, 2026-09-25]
mechanical/exports/base.step
140.0 x 100.0 x 55.0 mm

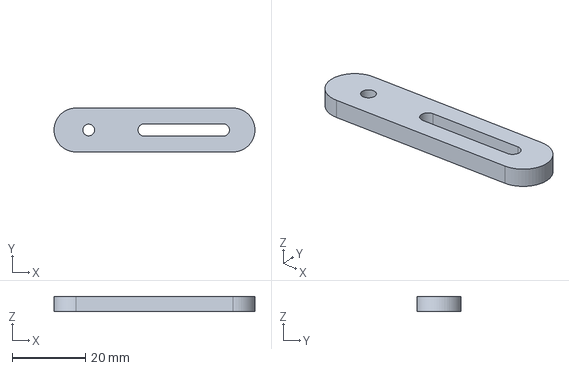
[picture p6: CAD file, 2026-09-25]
mechanical/exports/linkage_plate.step
55.0 x 12.0 x 4.00 mm

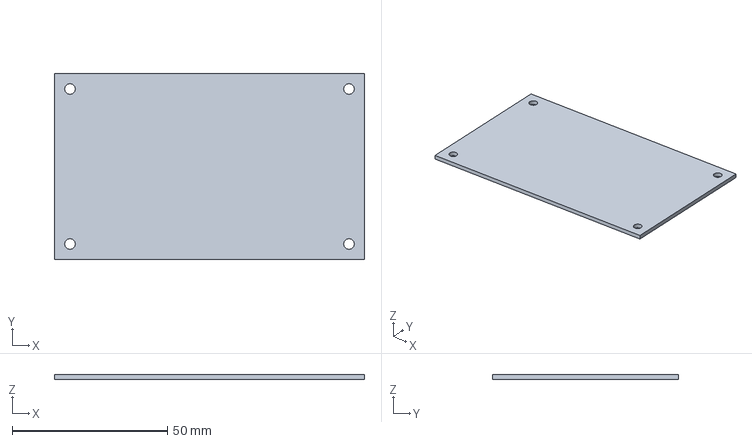
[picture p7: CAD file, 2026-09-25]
mechanical/exports/carrier_drill_template.step
100.0 x 60.0 x 1.60 mm

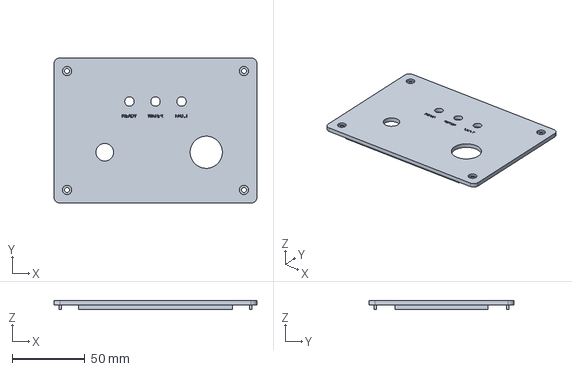
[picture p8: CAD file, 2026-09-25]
mechanical/exports/lid.step
140.0 x 100.0 x 6.00 mm

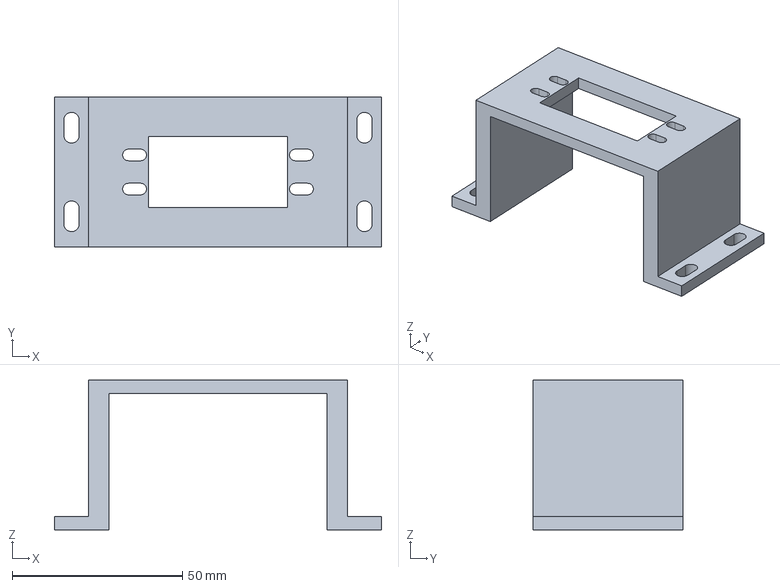
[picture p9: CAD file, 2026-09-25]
mechanical/exports/servo_bracket.step
96.0 x 44.0 x 44.0 mm

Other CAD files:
mechanical/exports/base.stl
mechanical/exports/carrier_drill_template.stl
mechanical/exports/lid.stl
mechanical/exports/linkage_plate.stl
mechanical/exports/servo_bracket.stl

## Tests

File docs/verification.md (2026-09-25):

# Rev A verification record

Date: 2026-09-25. These results concern generated files and software tests. No physical circuit, valve, probe, printed case, or water supply was connected during this work.

| Check | Result | Evidence |
|---|---|---|
| Native KiCad load and PDF/SVG export | Passed | `electronics/soil_valve.pdf`, `electronics/rendered/soil_valve.svg` |
| KiCad electrical rule check | **0 errors, 0 warnings** | [ERC report](../electronics/erc.rpt) |
| Exported connectivity | All 19 intended named nets matched | `tests/check_netlist.py`, XML netlist; 27 external schematic components |
| CAD solids | Five valid, single-solid parts | [Geometry report](../mechanical/exports/geometry_report.json) |
| Enclosure base/lid collision | 0 mm³ intersecting solid volume | Same geometry report; 0.3 mm nominal rail clearance |
| ESP32 firmware build | **Succeeded** | [Build log](firmware-build.log) |
| Firmware flash use | 825,757 / 1,310,720 bytes (63.0%) | PlatformIO size output |
| Firmware static RAM | 80,896 / 327,680 bytes (24.7%) | Excludes runtime heap and stack usage; hardware load test pending |
| Host C++ control tests | Passed | [Control test log](control-test.log) and `tests/control_test.cpp` |
| Browser integration | Passed with mocked device responses | [Browser log](browser-test.log) and `tests/browser_test.py` |
| Visual review | Schematic, exploded CAD and dashboard reviewed | Preview PNGs and SVGs in package |
| Hardware / hydraulic / environmental tests | **Not performed** | Execute [acceptance plan](audit-and-acceptance.md) |

## Versions and build details

- Windows PowerShell, Python 3.12.
- KiCad CLI 10.0.6; self-contained project symbol library.
- CadQuery 2.8.0; OpenCascade-backed kernel, STEP and STL exports.
- PlatformIO Core 6.2.0; Espressif32 platform 6.9.0.
- Arduino-ESP32 framework package `3.20017.241212+sha.dcc1105b` (Arduino 2.0.17).
- Xtensa compiler package `8.4.0+2021r2-patch5`, esptool 4.5.1.
- Zig 0.16.0 C++ frontend for host tests; Playwright 1.63.0 with installed Google Chrome for browser checks.

The first Windows firmware build hit a compiler process-launch error with the long workspace path. A temporary `R:` mapping of the same workspace resolved it; the final build completed in approximately 30 seconds and the mapping was removed. `tools/build_firmware.ps1` reproduces that workaround using a free drive letter and cleans it up afterward. No firmware source workaround was needed for this environment issue.

The initial host compiler generated warnings while building its bundled C++ standard library. The final incremental host build and application test run passed; these were tool-library diagnostics, not suppressed controller assertions. KiCad's sandboxed CLI also reported inability to write a per-user registry key, but schematic export and ERC completed with the report above.

## What the software checks establish

Control tests execute the actual portable `control.h` logic. Cases cover uncalibrated inhibition, five-second pulse termination, 60-second soak, demand hysteresis, STOP latch/reset, invalid sensor rejection, stale samples, six-pulse budget exhaustion and quiet-hour recovery, millisecond rollover, invalid configuration, and close/disarm. They do not emulate GPIO, PWM hardware, task scheduling, NVS flash failure, or valve motion.

Browser tests exercise the actual HTML/JavaScript. They check demo labeling and disabled controls, live status rendering, a threshold alert, arm/close request content and token header, mobile width, CSV gaps, and offline control inhibition; no JavaScript page errors were observed. Device responses are mocked. This establishes client behavior, not live ESP32 network performance or physical actuation.

CAD verification checks B-rep validity, one solid per part, positive volumes, and installed base/lid non-interference. It does not establish printed dimensions, fastener pullout strength, servo-flange fit, panel-component clearance, sealing, thermal performance, or lifetime.

ERC checks the external module circuit using explicitly declared source rails. It is not a simulation and cannot verify wire gauge, fuse behavior, analog accuracy, EMI, or the circuitry inside purchased modules. The report's listed ignored checks are the tool's baseline settings (e.g. SPICE-model issues), not exclusions added to hide this design's electrical errors.

## Artifact integrity

`docs/manifest-sha256.json` records hashes of all packaged source and deliverable files except itself. `tools/make_release.py` creates the manifest and ZIP and checks relative Markdown links and ZIP integrity. Private credentials, local compiler caches, and firmware binaries are excluded from the shared ZIP. A locally built firmware binary is available under `firmware/.pio/build/esp32dev/` and contains the local credentials; rebuild with deployment-specific secrets rather than distributing it indiscriminately.

The final audit must identify the exact flashed binary and physical hardware, not just the package revision. Record those hashes and component serial/lot identifiers alongside the bench results.

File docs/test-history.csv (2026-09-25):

seconds_since_boot | relative_moisture_pct | adc_mv | valve_command_open
60 | 40 | 1300 | false
120 |  | 0 | false
180 | 28.5 | 1386 | false

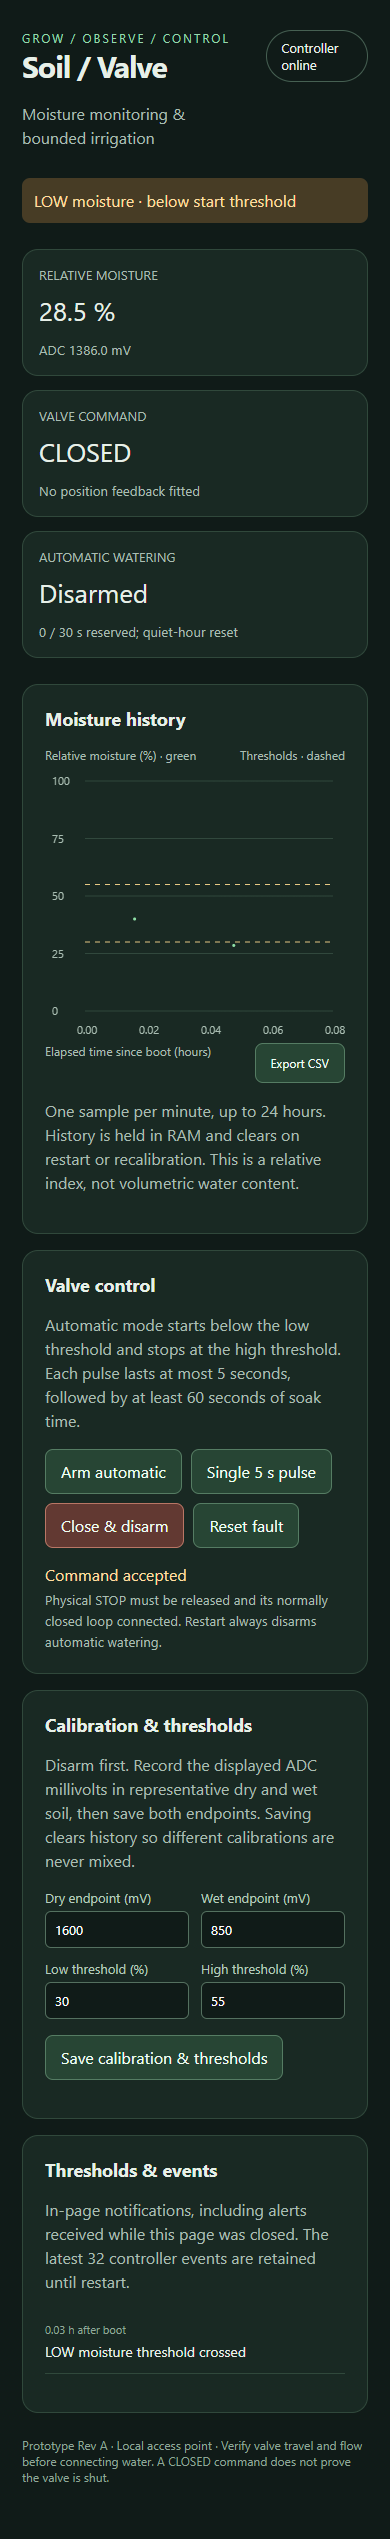
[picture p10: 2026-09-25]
docs/dashboard-mobile-test.png

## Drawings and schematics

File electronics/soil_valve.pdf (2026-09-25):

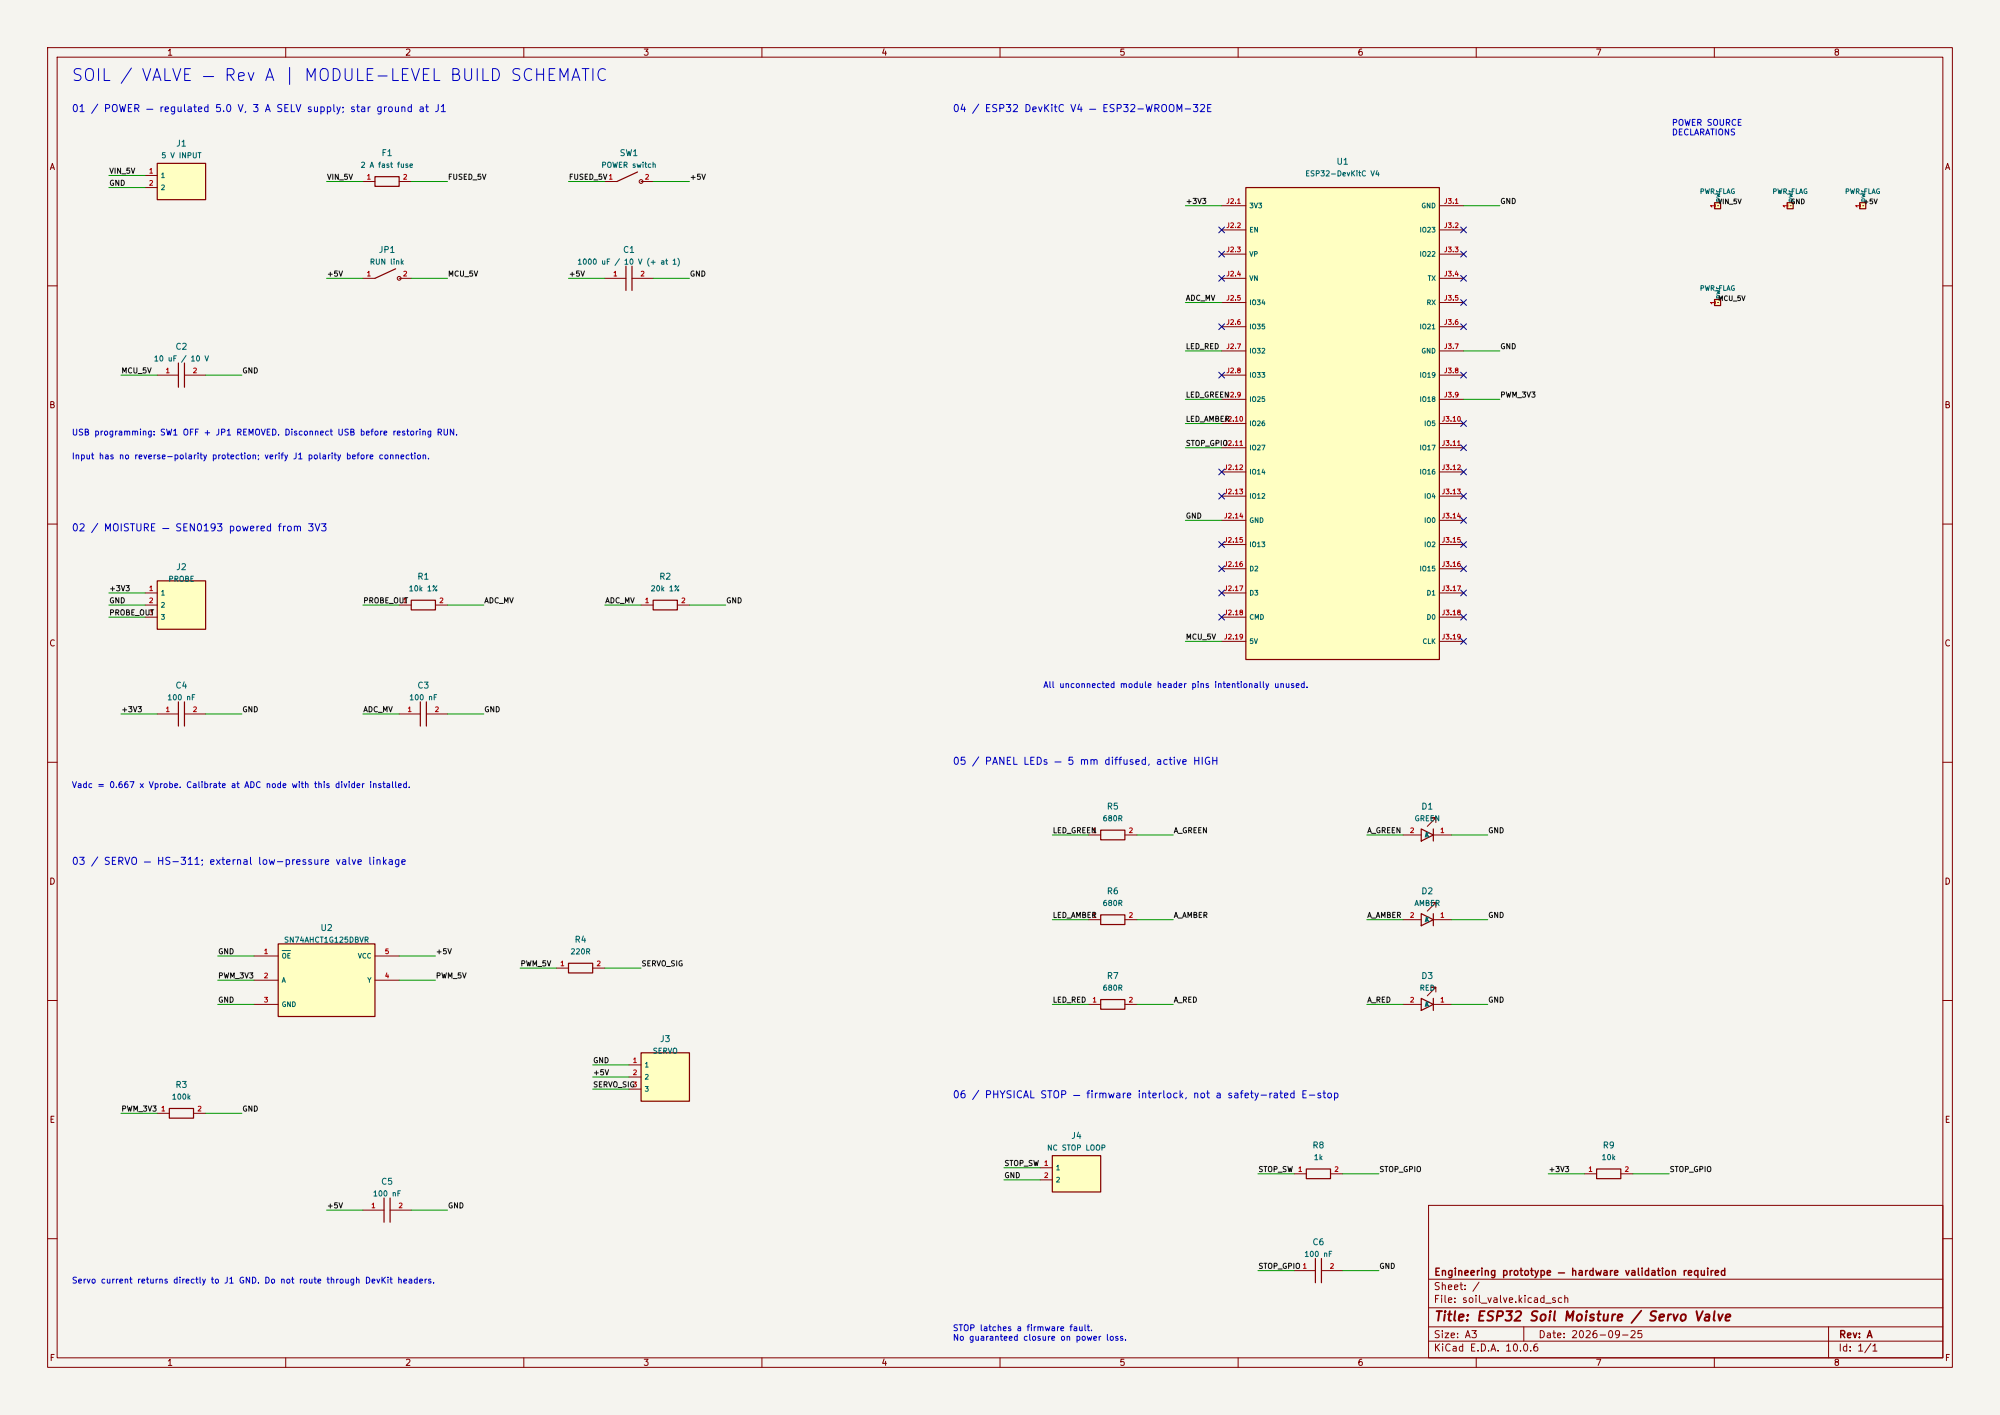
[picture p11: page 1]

SOIL / VALVE — Rev A | MODULE-LEVEL BUILD SCHEMATIC

01 / POWER — regulated 5.0 V, 3 A SELV supply; star ground at J1
2 A fast fuse 1

04 / ESP32 DevKitC V4 — ESP32-WROOM-32E
POWER SOURCE DECLARATIONS 05 / PANEL LEDs — 5 mm diffused, active HIGH

All unconnected module header pins intentionally unused. USB programming: SW1 OFF + JP1 REMOVED. Disconnect USB before restoring RUN. 02 / MOISTURE — SEN0193 powered from 3V3

Input has no reverse-polarity protection; verify J1 polarity before connection.

Vadc = 0.667 x Vprobe. Calibrate at ADC node with this divider installed.

03 / SERVO — HS-311; external low-pressure valve linkage

Engineering prototype — hardware validation required
Sheet: /
File: soil_valve.kicad_sch
Title: ESP32 Soil Moisture / Servo Valve

STOP latches a firmware fault. No guaranteed closure on power loss.

Size: A3 | Rev: A | F Date: 2026-09-25
KiCad E.D.A. 10.0.6 | Id: 1/1

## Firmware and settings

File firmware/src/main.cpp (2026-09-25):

#include <Arduino.h>
#include <WiFi.h>
#include <WebServer.h>
#include <Preferences.h>
#include <esp_task_wdt.h>
#include "control.h"
#include "ui.h"
#if __has_include("secrets.h")
#include "secrets.h"
#else
#error "Copy include/secrets.example.h to include/secrets.h and set unique passwords."
#endif

constexpr int ADC_PIN=34, SERVO_PIN=18, GREEN=25, AMBER=26, RED=32, STOP_PIN=27;
// Commission with horn disconnected. HS-311 nominal +/-60 deg is 900..2100 us.
constexpr int CLOSED_US=1050, OPEN_US=1950, PWM_CHANNEL=0;
constexpr size_t HISTORY_N=1440, EVENT_N=32;
struct Point { uint64_t sec; float pct,mv; bool valid,open; };
struct Event { uint64_t sec; String message; };
soil::Controller ctl;
Point history[HISTORY_N]; Event events[EVENT_N];
size_t histHead=0,histCount=0,eventHead=0,eventCount=0;
uint64_t upMs=0; uint32_t previousMs=0;
SemaphoreHandle_t lock;
WebServer server(80);
String csrf, bootId;
bool storageOK=true, controlOK=false;
void event(const String& s) { events[eventHead]={upMs/1000,s}; eventHead=(eventHead+1)%EVENT_N; if(eventCount<EVENT_N) ++eventCount; }
void pwm(bool open) { ledcWrite(PWM_CHANNEL, uint32_t((open?OPEN_US:CLOSED_US)*65535UL/20000UL)); }
void controlTask(void*) {
  esp_task_wdt_add(nullptr);
  uint32_t sampleAt=millis()-250, logAt=millis()-60000;
  bool wasOpen=false, wasArmed=false; soil::Fault wasFault=soil::Fault::None; int zone=-1;
  for(;;) {
    uint32_t now=millis();
    bool takeSample=uint32_t(now-sampleAt)>=250;
    float value=0;
    if(takeSample) { for(int i=0;i<16;++i) value+=analogReadMilliVolts(ADC_PIN); value/=16; sampleAt=now; }
    xSemaphoreTake(lock,portMAX_DELAY);
    now=millis(); // Commands may have changed timestamps while ADC sampling ran.
    upMs+=uint32_t(now-previousMs); previousMs=now;
    if(takeSample) ctl.sample(value,now);
    ctl.tick(now,digitalRead(STOP_PIN)==HIGH);
    pwm(ctl.opening);
    digitalWrite(GREEN,ctl.armed?HIGH:((now/1000)%2));
    digitalWrite(AMBER,ctl.opening);
    digitalWrite(RED,ctl.fault!=soil::Fault::None || !ctl.cfg.calibrated || !storageOK);
    if(ctl.opening!=wasOpen) { event(ctl.opening?"Valve commanded OPEN":"Valve commanded CLOSED"); wasOpen=ctl.opening; }
    if(ctl.armed!=wasArmed) { event(ctl.armed?"Automatic watering armed":"Automatic watering disarmed"); wasArmed=ctl.armed; }
    if(ctl.fault!=wasFault) { event(ctl.fault==soil::Fault::None?"Fault reset":String("FAULT: ")+soil::faultName(ctl.fault)); wasFault=ctl.fault; }
    if(ctl.good && ctl.cfg.calibrated) {
      int next=ctl.moisture<ctl.cfg.low?0:(ctl.moisture>=ctl.cfg.high?2:1);
      if(next!=zone) { event(next==0?"LOW moisture threshold crossed":next==2?"HIGH moisture threshold reached":"Moisture in target band"); zone=next; }
    }
    if(uint32_t(now-logAt)>=60000) {
      history[histHead]={upMs/1000,ctl.moisture,ctl.mv,ctl.good&&ctl.cfg.calibrated,ctl.opening};
      histHead=(histHead+1)%HISTORY_N; if(histCount<HISTORY_N) ++histCount; logAt=now;
    }
    xSemaphoreGive(lock);
    esp_task_wdt_reset();
    vTaskDelay(pdMS_TO_TICKS(20));
  }
}
bool auth(bool mutation=false) {
  if(!server.authenticate("admin",ADMIN_PASSWORD)) { server.requestAuthentication(); return false; }
  server.sendHeader("Cache-Control","no-store");
  server.sendHeader("X-Content-Type-Options","nosniff");
  if(mutation && server.header("X-Control-Token")!=csrf) { server.send(403,"text/plain","Invalid control token"); return false; }
  return true;
}
String number64(uint64_t n) { char b[24]; snprintf(b,sizeof(b),"%llu",(unsigned long long)n); return String(b); }
void status() {
  if(!auth()) return;
  xSemaphoreTake(lock,portMAX_DELAY);
  auto c=ctl; auto sec=upMs/1000;
  String ev="[";
  for(size_t i=0;i<eventCount;++i) {auto& e=events[(eventHead+EVENT_N-eventCount+i)%EVENT_N]; if(i) ev+=","; ev+="{\"s\":"+number64(e.sec)+",\"message\":\""+e.message+"\"}";}
  ev+="]";
  xSemaphoreGive(lock);
  String out="{\"boot\":\""+bootId+"\",\"token\":\""+csrf+"\",\"s\":"+number64(sec);
  out+=",\"moisture\":"+String(c.moisture,1)+",\"mv\":"+String(c.mv,1);
  out+=",\"valid\":"+String(c.good&&c.cfg.calibrated?"true":"false")+",\"armed\":"+String(c.armed?"true":"false");
  out+=",\"open\":"+String(c.opening?"true":"false")+",\"fault\":\""+soil::faultName(c.fault)+"\"";
  out+=",\"calibrated\":"+String(c.cfg.calibrated?"true":"false")+",\"storageOK\":"+String(storageOK?"true":"false");
  out+=",\"low\":"+String(c.cfg.low)+",\"high\":"+String(c.cfg.high)+",\"dryMv\":"+String(c.cfg.dryMv)+",\"wetMv\":"+String(c.cfg.wetMv);
  out+=",\"reservedSeconds\":"+String(c.reserved/1000)+",\"events\":"+ev+"}";
  server.send(200,"application/json",out);
}
void historyGet() {
  if(!auth()) return;
  // Copy under the lock; network transmission never holds the control lock.
  Point* copy=new(std::nothrow) Point[HISTORY_N];
  if(!copy) {server.send(503,"text/plain","Memory busy");return;}
  xSemaphoreTake(lock,portMAX_DELAY); size_t count=histCount;
  for(size_t i=0;i<count;++i) copy[i]=history[(histHead+HISTORY_N-count+i)%HISTORY_N];
  xSemaphoreGive(lock);
  server.setContentLength(CONTENT_LENGTH_UNKNOWN); server.send(200,"application/json",""); server.sendContent("[");
  String chunk; chunk.reserve(1600);
  for(size_t i=0;i<count;++i) {
    if(i) chunk+=",";
    chunk+="{\"s\":"+number64(copy[i].sec)+",\"pct\":"+(copy[i].valid?String(copy[i].pct,1):String("null"));
    chunk+=",\"mv\":"+String(copy[i].mv,1)+",\"open\":"+String(copy[i].open?"true":"false")+"}";
    if(chunk.length()>1200) {server.sendContent(chunk);chunk="";}
  }
  chunk+="]"; server.sendContent(chunk); server.sendContent(""); delete[] copy;
}
bool parseNumber(const char* key,float& v) {
  if(!server.hasArg(key)) return false;
  String s=server.arg(key); char* end=nullptr; v=strtof(s.c_str(),&end);
  return end!=s.c_str() && *end=='\0' && isfinite(v);
}
void configure() {
  if(!auth(true)) return;
  soil::Config next;
  if(!parseNumber("dryMv",next.dryMv)||!parseNumber("wetMv",next.wetMv)||!parseNumber("low",next.low)||!parseNumber("high",next.high)||!next.valid()) {
    server.send(400,"text/plain","Require 100 <= wet < dry <= 2150 mV; span >= 200; 5 <= low < high <= 95; gap >= 5"); return;
  }
  next.calibrated=true;
  xSemaphoreTake(lock,portMAX_DELAY);
  bool busy=ctl.opening||ctl.armed;
  xSemaphoreGive(lock);
  if(busy) {server.send(409,"text/plain","Disarm and close before changing calibration");return;}
  Preferences p;
  bool ok=p.begin("soil",false);
  if(ok) {ok=p.putBytes("config",&next,sizeof(next))==sizeof(next);p.end();}
  xSemaphoreTake(lock,portMAX_DELAY); storageOK=ok; xSemaphoreGive(lock);
  if(!ok) {server.send(500,"text/plain","Configuration persistence failed");return;}
  xSemaphoreTake(lock,portMAX_DELAY); ctl.cfg=next; ctl.good=false; ctl.goodCount=0; histCount=0;histHead=0;
  event("Calibration saved; history cleared; remains disarmed"); xSemaphoreGive(lock);
  server.send(200,"text/plain","Saved. Wait for fresh samples before arming.");
}
void command() {
  if(!auth(true)) return;
  String action=server.arg("action"); bool ok=false;
  xSemaphoreTake(lock,portMAX_DELAY); uint32_t now=millis();
  // Recheck the physical input synchronously before accepting a command.
  ctl.tick(now,digitalRead(STOP_PIN)==HIGH);
  if(action=="close") {ctl.disarm(now);ok=true;}
  else if(action=="arm") ok=storageOK&&ctl.arm(now);
  else if(action=="pulse") ok=storageOK&&!ctl.armed&&ctl.manual(now);
  else if(action=="reset") ok=ctl.reset(now);
  if(ok) event("UI command: "+action);
  xSemaphoreGive(lock);
  server.send(ok?200:409,"text/plain",ok?"Command accepted":"Blocked: check calibration, fault, STOP loop, soak timer, budget, and mode");
}
void setup() {
  Serial.begin(115200);
  pinMode(STOP_PIN,INPUT_PULLUP);
  for(int pin:{GREEN,AMBER,RED}) {pinMode(pin,OUTPUT);digitalWrite(pin,LOW);}
  pinMode(SERVO_PIN,OUTPUT);digitalWrite(SERVO_PIN,LOW);
  ledcSetup(PWM_CHANNEL,50,16);ledcAttachPin(SERVO_PIN,PWM_CHANNEL);pwm(false);
  analogReadResolution(12);analogSetPinAttenuation(ADC_PIN,ADC_11db);
  lock=xSemaphoreCreateMutex(); if(!lock) {digitalWrite(RED,HIGH);return;}
  Preferences p;
  if(p.begin("soil",true)) {
    soil::Config saved;
    if(p.getBytesLength("config")==sizeof(saved) && p.getBytes("config",&saved,sizeof(saved))==sizeof(saved) && saved.valid()) ctl.cfg=saved;
    p.end();
  }
  ctl.closedAt=millis(); previousMs=millis();
  event("Boot: CLOSED command; automatic watering disarmed");
  esp_task_wdt_init(3,true);
  controlOK=xTaskCreatePinnedToCore(controlTask,"control",6144,nullptr,3,nullptr,1)==pdPASS;
  if(!controlOK) {digitalWrite(RED,HIGH);return;}
  if(strlen(AP_PASSWORD)<12 || strlen(ADMIN_PASSWORD)<12 || strstr(AP_PASSWORD,"replace-") || strstr(ADMIN_PASSWORD,"replace-")) {
    Serial.println("Set unique passwords, >=12 characters. Network disabled."); return;
  }
  WiFi.mode(WIFI_AP);
  String ssid="SoilValve-"+String(uint32_t(ESP.getEfuseMac()),HEX);
  if(!WiFi.softAP(ssid.c_str(),AP_PASSWORD)) {Serial.println("AP failed; control remains disarmed");return;}
  bootId=String(esp_random(),HEX); csrf=String(esp_random(),HEX)+String(esp_random(),HEX)+String(esp_random(),HEX)+String(esp_random(),HEX);
  const char* headers[]={"X-Control-Token"};server.collectHeaders(headers,1);
  server.on("/",HTTP_GET,[]{if(auth())server.send_P(200,"text/html",UI);});
  server.on("/api/status",HTTP_GET,status); server.on("/api/history",HTTP_GET,historyGet);
  server.on("/api/config",HTTP_POST,configure);server.on("/api/command",HTTP_POST,command);
  server.onNotFound([]{server.send(404,"text/plain","Not found");});server.begin();
  Serial.printf("Connect to %s, open http://192.168.4.1 (admin).\n",ssid.c_str());
}
void loop() {if(controlOK)server.handleClient();delay(2);}

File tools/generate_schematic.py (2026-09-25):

"""Generate a self-contained KiCad schematic; no third-party symbol library needed."""
from pathlib import Path
import uuid, json, csv
ROOT=Path(__file__).resolve().parents[1]
OUT=ROOT/'electronics'; OUT.mkdir(exist_ok=True)
uid=lambda:str(uuid.uuid4())
def q(s): return json.dumps(str(s),ensure_ascii=False)
def effect(size=1.27,other=''): return f'(effects (font (size {size} {size})) {other})'
libs={}; components=[]; items=[]; rootid=uid(); nets={}
def library(name,pins,shape='box',width=12.7,height=None):
    h=height or max(5.08,len(pins)*1.27)
    if shape=='resistor': drawing='(rectangle (start -2.54 -1.016) (end 2.54 1.016) (stroke (width 0.254) (type default)) (fill (type none)))'
    elif shape=='capacitor': drawing=''.join(f'(polyline (pts (xy {x} -2.54) (xy {x} 2.54)) (stroke (width 0.254) (type default)) (fill (type none)))' for x in [-.635,.635])
    elif shape=='led': drawing='(polyline (pts (xy -1.27 -1.27) (xy 1.27 0) (xy -1.27 1.27) (xy -1.27 -1.27)) (stroke (width 0.254) (type default)) (fill (type none))) (polyline (pts (xy 1.27 -1.27) (xy 1.27 1.27)) (stroke (width 0.254) (type default)) (fill (type none))) (polyline (pts (xy 0 1.8) (xy 1.8 3.6) (xy 0.8 3.6) (xy 1.8 3.6) (xy 1.8 2.6)) (stroke (width 0.15) (type default)) (fill (type none)))'
    elif shape=='switch': drawing='(polyline (pts (xy -2.54 0) (xy 1.8 2)) (stroke (width 0.254) (type default)) (fill (type none))) (circle (center 2.54 0) (radius 0.4) (stroke (width 0.15) (type default)) (fill (type none)))'
    else: drawing=f'(rectangle (start {-width/2} {-h/2}) (end {width/2} {h/2}) (stroke (width 0.254) (type default)) (fill (type background)))'
    ps=[]
    for num,label,x,y,angle,kind,length in pins:
        ps.append(f'(pin {kind} line (at {x} {y} {angle}) (length {length}) (name {q(label)} {effect(1.0)}) (number {q(num)} {effect(1.0)}))')
    libs[name]=f'(symbol "Soil:{name}" (pin_names (offset 0.635)) (in_bom yes) (on_board yes) (property "Reference" "U" (at 0 0 0) {effect()}) (property "Value" {q(name)} (at 0 0 0) {effect()}) (symbol "{name}_0_1" {drawing}) (symbol "{name}_1_1" {"".join(ps)}))'
    return pins
two=[('1','',-5.08,0,0,'passive',2.54),('2','',5.08,0,180,'passive',2.54)]
library('R',two,'resistor');library('Fuse',two,'resistor');library('Link',two,'switch')
cap=[('1','',-5.08,0,0,'passive',4.445),('2','',5.08,0,180,'passive',4.445)]
library('C',cap,'capacitor')
led=[('2','A',-5.08,0,0,'passive',3.81),('1','K',5.08,0,180,'passive',3.81)]
library('LED',led,'led')
for n in [2,3]:
    library('Conn'+str(n),[(str(i+1),str(i+1),-7.62,(n-1)*2.54/2-i*2.54,0,'passive',2.54) for i in range(n)],width=10.16,height=n*2.54+2.54)
buf=[('1','~{OE}',-15.24,5.08,0,'input',5.08),('2','A',-15.24,0,0,'input',5.08),('3','GND',-15.24,-5.08,0,'power_in',5.08),('4','Y',15.24,0,180,'output',5.08),('5','VCC',15.24,5.08,180,'power_in',5.08)]
library('AHCT125',buf,width=20.32,height=15.24)
left=['3V3','EN','VP','VN','IO34','IO35','IO32','IO33','IO25','IO26','IO27','IO14','IO12','GND','IO13','D2','D3','CMD','5V']
right=['GND','IO23','IO22','TX','RX','IO21','GND','IO19','IO18','IO5','IO17','IO16','IO4','IO0','IO2','IO15','D1','D0','CLK']
mcu=[]
for side,names,x,a in [('J2',left,-25.4,0),('J3',right,25.4,180)]:
    for i,name in enumerate(names):
        typ='power_in' if name in ['GND','5V'] else 'power_out' if name=='3V3' else 'input' if name in ['IO34','IO35','VP','VN','EN'] else 'bidirectional'
        mcu.append((f'{side}.{i+1}',name,x,45.72-i*5.08,a,typ,5.08))
library('DevKitC_V4',mcu,width=40.64,height=99.06)
def text(s,x,y,size=1.5): items.append(f'(text {q(s)} (at {x} {y} 0) {effect(size,"(justify left)")} (uuid {uid()}))')
def component(ref,kind,value,x,y,connections,desc,footprint=''):
    pins={'R':two,'Fuse':two,'Link':two,'C':cap,'LED':led,'AHCT125':buf,'DevKitC_V4':mcu}.get(kind)
    if pins is None:
        n=int(kind[-1]);pins=[(str(i+1),str(i+1),-7.62,(n-1)*2.54/2-i*2.54,0,'passive',2.54) for i in range(n)]
    sid=uid()
    offset=55 if kind=='DevKitC_V4' else 11 if kind=='AHCT125' else 8 if kind.startswith('Conn') else 6
    items.append(f'(symbol (lib_id "Soil:{kind}") (at {x} {y} 0) (unit 1) (in_bom yes) (on_board yes) (dnp no) (uuid {sid}) (property "Reference" {q(ref)} (at {x} {y-offset} 0) {effect()}) (property "Value" {q(value)} (at {x} {y-offset+2.54} 0) {effect(1.1)}) (property "Footprint" {q(footprint)} (at {x} {y} 0) {effect(1.27,"(hide yes)")}) '+''.join(f'(pin {q(p[0])} (uuid {uid()}))' for p in pins)+f'(instances (project "soil_valve" (path "/{rootid}" (reference {q(ref)}) (unit 1)))))')
    components.append({'reference':ref,'value':value,'description':desc,'footprint':footprint})
    for num,label,dx,dy,angle,typ,length in pins:
        px,py=round(x+dx,4),round(y-dy,4)
        net=connections.get(num)
        if net is None:
            items.append(f'(no_connect (at {px} {py}) (uuid {uid()}))');continue
        ex=round(px+(-7.62 if dx<0 else 7.62),4)
        items.append(f'(wire (pts (xy {px} {py}) (xy {ex} {py})) (stroke (width 0) (type default)) (uuid {uid()}))')
        items.append(f'(label {q(net)} (at {ex} {py} 0) {effect(1.1,"(justify left bottom)")} (uuid {uid()}))')
        nets.setdefault(net,[]).append([ref,num])
def pair(ref,kind,value,x,y,a,b,desc):component(ref,kind,value,x,y,{'1':a,'2':b},desc)
text('SOIL / VALVE — Rev A | MODULE-LEVEL BUILD SCHEMATIC',15,16,2.5)
text('01 / POWER — regulated 5.0 V, 3 A SELV supply; star ground at J1',15,23)
component('J1','Conn2','5 V INPUT',38.1,38.1,{'1':'VIN_5V','2':'GND'},'Keyed 2-pin supply connector, >=3 A; pin 1 positive')
pair('F1','Fuse','2 A fast fuse',81.28,38.1,'VIN_5V','FUSED_5V','Replaceable 2 A fuse, rated >=32 VDC')
pair('SW1','Link','POWER switch',132.08,38.1,'FUSED_5V','+5V','SPST maintained switch >=3 A DC')
pair('JP1','Link','RUN link',81.28,58.42,'+5V','MCU_5V','Remove this jumper AND switch external power OFF before USB connection')
pair('C1','C','1000 uF / 10 V (+ at 1)',132.08,58.42,'+5V','GND','Low ESR electrolytic, positive terminal pin 1, near servo connector')
pair('C2','C','10 uF / 10 V',38.1,78.74,'MCU_5V','GND','MCU input bulk capacitor')
text('USB programming: SW1 OFF + JP1 REMOVED. Disconnect USB before restoring RUN.',15,91,1.25)
text('Input has no reverse-polarity protection; verify J1 polarity before connection.',15,96,1.25)
text('02 / MOISTURE — SEN0193 powered from 3V3',15,111)
component('J2','Conn3','PROBE',38.1,127,{'1':'+3V3','2':'GND','3':'PROBE_OUT'},'Board harness: 1=3V3 2=GND 3=analog; verify sensor cable mapping')
pair('R1','R','10k 1%',88.9,127,'PROBE_OUT','ADC_MV','ADC divider top resistor')
pair('R2','R','20k 1%',139.7,127,'ADC_MV','GND','ADC divider bottom resistor, disconnect pulls ADC low')
pair('C3','C','100 nF',88.9,149.86,'ADC_MV','GND','ADC low pass capacitor at GPIO34')
pair('C4','C','100 nF',38.1,149.86,'+3V3','GND','Probe supply decoupling at connector')
text('Vadc = 0.667 x Vprobe. Calibrate at ADC node with this divider installed.',15,165,1.25)
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
